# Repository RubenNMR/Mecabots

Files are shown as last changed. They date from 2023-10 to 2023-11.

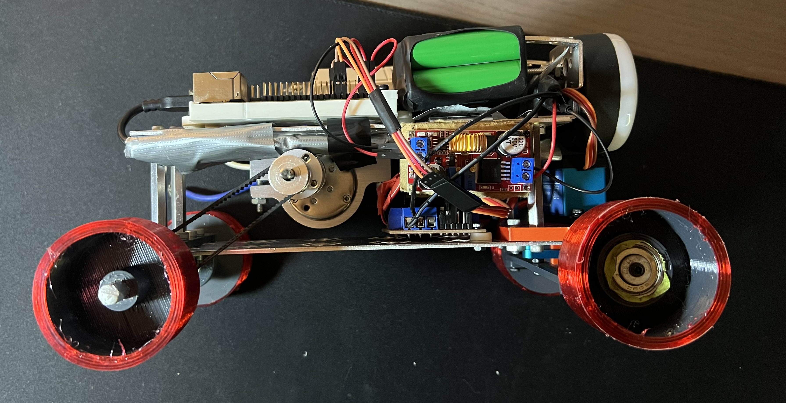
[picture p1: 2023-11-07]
v-photos/IMG_0404.jpeg

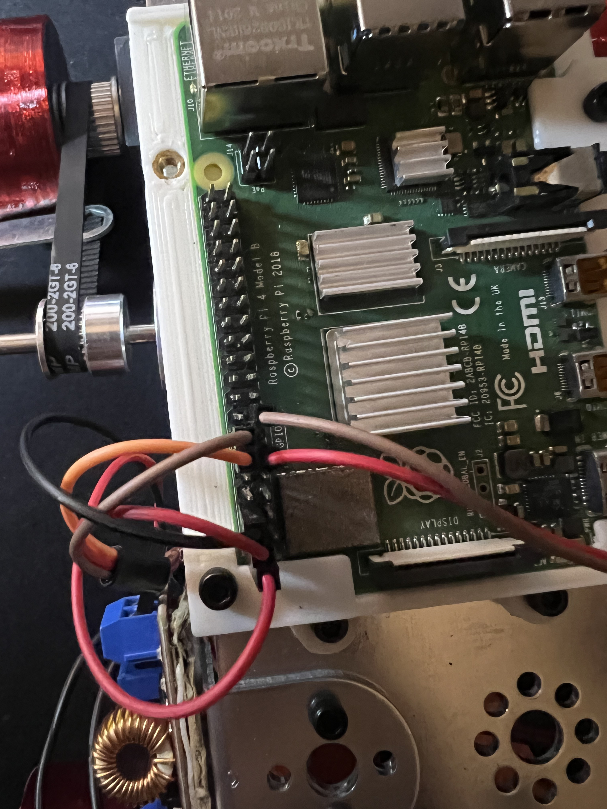
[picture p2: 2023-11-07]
v-photos/IMG_0406.jpeg

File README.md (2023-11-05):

# Vehicle Project README

## Introduction

In the making of the vehicle, we encountered many challenges that we eventually overcame. One of those challenges was the design itself. We had numerous source materials to base our project on, but we decided to innovate. We took two aluminum plates from a Tetrix kit and a motor. After we had the base, our team started a trial and error process in which we decided on our current design. The design adheres to all of the requirements of the WRO.

## Mechanical Design

When the base was completed, we started to create the front of the vehicle and all of the mechanical aspects of the steering mechanism. We designed it in SolidWorks with the help of a partner. We gave him the instructions and he assisted us with the technical aspects of using SolidWorks. Along the way, we encountered a problem with the inner workings of the steering mechanism. The issue was that the servo motor shaft was off the original position. While not immediately noticeable, we brainstormed and quickly resolved it. In the end, we sent all of the pieces to a slicer and to a 3D printer to be made.

## Construction and Adaptations

After the pieces arrived, we began the construction of the vehicle. As we progressed, we made some adjustments and changes in the design to accommodate newer parts like the motor. The motor had a shaft of 6mm, while our pulley connector was 4mm in diameter, making them incompatible. However, we were able to create an adapter using aluminum pieces that remained from the Tetrix kit.

## Software and Hardware Integration

At this point, we were simultaneously working on the software and hardware, making clear the requirements for each part and communicating any modifications that could affect either side.

## Platform Decision

We initially planned to create an Arduino white driver / Raspberry Pi hybrid, using the Arduino as a motor driver with connections to the Raspberry Pi interface, which was supposed to process and recognize obstacles. However, in the end, we decided to use only a Raspberry Pi, motor driver, and a camera. This streamlined the programming process as it was focused on a single platform.

## Power Management

To address power compatibility, we installed the motor driver's power IN into the battery and then the control pins into the Raspberry Pi. However, the Raspberry Pi can only be powered by 5 volts, not 12 volts. To overcome this, we first created a voltage regulator to reduce the output to the Raspberry Pi. After initial testing, we later purchased a more powerful and precise regulator.

## Adding Vision

With the energy source issue resolved, we needed to equip the vehicle with "eyes" - a webcam. We modified it to be more compact and easy to work with.

## Completion and Reflection

In the end, this machine was finally completed with the help of many people and a team that was united, with each member specializing in their field of knowledge but also being open to help in any way possible. This journey has led us to expand our minds and inspire us to keep pursuing what we love. We presented this project to many people, including other members of the university and even to companies like Samsung DR. However, the people who remain the most impressed by it are us, the creators: Angel Veloz, Eudy Moreno, and Ruben Martinez. We never believed that in less than one and a half months in the university, we would be creating this vehicle, and we appreciate everything. Our journey has only just begun.

## Team Information

**Names:** Angel Veloz, Eudy Moreno, Ruben Martinez

**University:** PUCMM (Pontificia Universidad Católica Madre y Maestra), Dominican Republic

**Program:** Mechatronic Engineering

## Acknowledgements

We would like to express our gratitude to the specialists in the University, including the professor of advanced Robotics, and many of the seniors who provided us with invaluable help and guidance throughout our journey.

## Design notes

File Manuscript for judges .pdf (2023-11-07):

## PONTIFICIA UNIVERSIDAD CATOLICA MADRE Y MAESTRA (PUCMM)

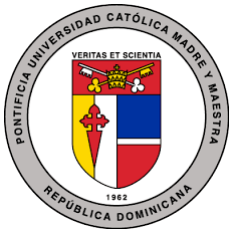
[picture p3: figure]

TEAM NAME:
MECABOT

CAREER:
MECHATRONIC ENGINEERING (IMEC)

TRAVEL MANUSCRIPT
WRO Competition

TEACHER:

IMEC DIRECTOR (JESÚS RAMÍREZ DE NAZARET)

DATE:
05/11/23 - 09/11/23

In this travel manuscript you will find the purpose of the trip, functionality of the device on board, parts with their respective links and our journey that lead us to this day.

- Materials list:
- Raspberry Pi Gen 4 (Laptop)
- Motor driver 12 volts (Motor controller)
- Energy regulator (12v - 5v energy regulator)
- Servo Motor (25kg)
- 1080p camera (generic) No link

——————————————————————————————————————————

In the making of the vehicle, we encountered many challenges that we eventually overcame. One of those challenges was the design itself. We had numerous source materials to base our project on, but we decided to innovate. We took two aluminum plates from a Tetrix kit and a motor. After we had the base, our team started a trial and error process in which we decided on our current design. The design adheres to all of the requirements of the WRO.

Mechanical Design (https://github.localhost/#mechanical-design)

When the base was completed, we started to create the front of the vehicle and all of the mechanical aspects of the steering mechanism. We designed it in SolidWorks with the help of a partner. We gave him the instructions and he assisted us with the technical aspects of using SolidWorks. Along the way, we encountered a problem with the inner workings of the steering mechanism. The issue was that the servo motor shaft was off the original position. While not immediately noticeable, we brainstormed and quickly resolved it. In the end, we sent all of the pieces to a slicer and to a 3D printer to be made.

Construction and Adaptations (https://github.localhost/#construction-and-adaptations)

After the pieces arrived, we began the construction of the vehicle. As we progressed, we made some adjustments and changes in the design to accommodate newer parts like the motor. The motor had a shaft of 6mm, while our pulley connector was 4mm in diameter, making them incompatible. However, we were able to create an adapter using aluminum pieces that remained from the Tetrix kit.

Software and Hardware Integration (https://github.localhost/#software-and-hardware-integration)

At this point, we were simultaneously working on the software and hardware, making clear the requirements for each part and communicating any modifications that could affect either side.

Platform Decision (https://github.localhost/#platform-decision)

We initially planned to create an Arduino white driver / Raspberry Pi hybrid, using the Arduino as a motor driver with connections to the Raspberry Pi interface, which was supposed to process and recognize obstacles. However, in the end, we decided to use only a Raspberry Pi, motor driver, and a camera. This streamlined the programming process as it was focused on a single platform.

Power Management (https://github.localhost/#power-management)

To address power compatibility, we installed the motor driver's power IN into the battery and then the control pins into the Raspberry Pi. However, the Raspberry Pi can only be powered by 5 volts, not 12 volts. To overcome this, we first created a voltage regulator to reduce the output to the Raspberry Pi. After initial testing, we later purchased a more powerful and precise regulator.

Adding Vision (https://github.localhost/#adding-vision)

With the energy source issue resolved, we needed to equip the vehicle with "eyes" - a webcam. We modified it to be more compact and easy to work with.

Completion and Reflection (https://github.localhost/#completion-and-reflection)

In the end, this machine was finally completed with the help of many people and a team that was united, with each member specializing in their field of knowledge but also being open to help in any way possible. This journey has led us to expand our minds and inspire us to keep pursuing what we love. We presented this project to many people, including other members of the university and even to companies like Samsung DR. However, the people who remain the most impressed by it are us, the creators: Angel Veloz, Eudy Moreno, and Ruben Martinez. We never believed that in less than one and a half months in the university, we would be creating this vehicle, and we appreciate everything. Our journey has only just begun.

Team Information (https://github.localhost/#team-information)

Names: Angel Veloz, Eudy Moreno, Ruben Martinez

University: PUCMM (Pontificia Universidad Católica Madre y Maestra), Dominican Republic

Program: Mechatronic Engineering

Acknowledgements (https://github.localhost/#acknowledgements)

We would like to express our gratitude to the specialists in the University, including the professor of advanced Robotics, and many of the seniors who provided us with invaluable help and guidance throughout our journey.

The following QR codes are meant to lead you to plataformas with more information about our vehicle.

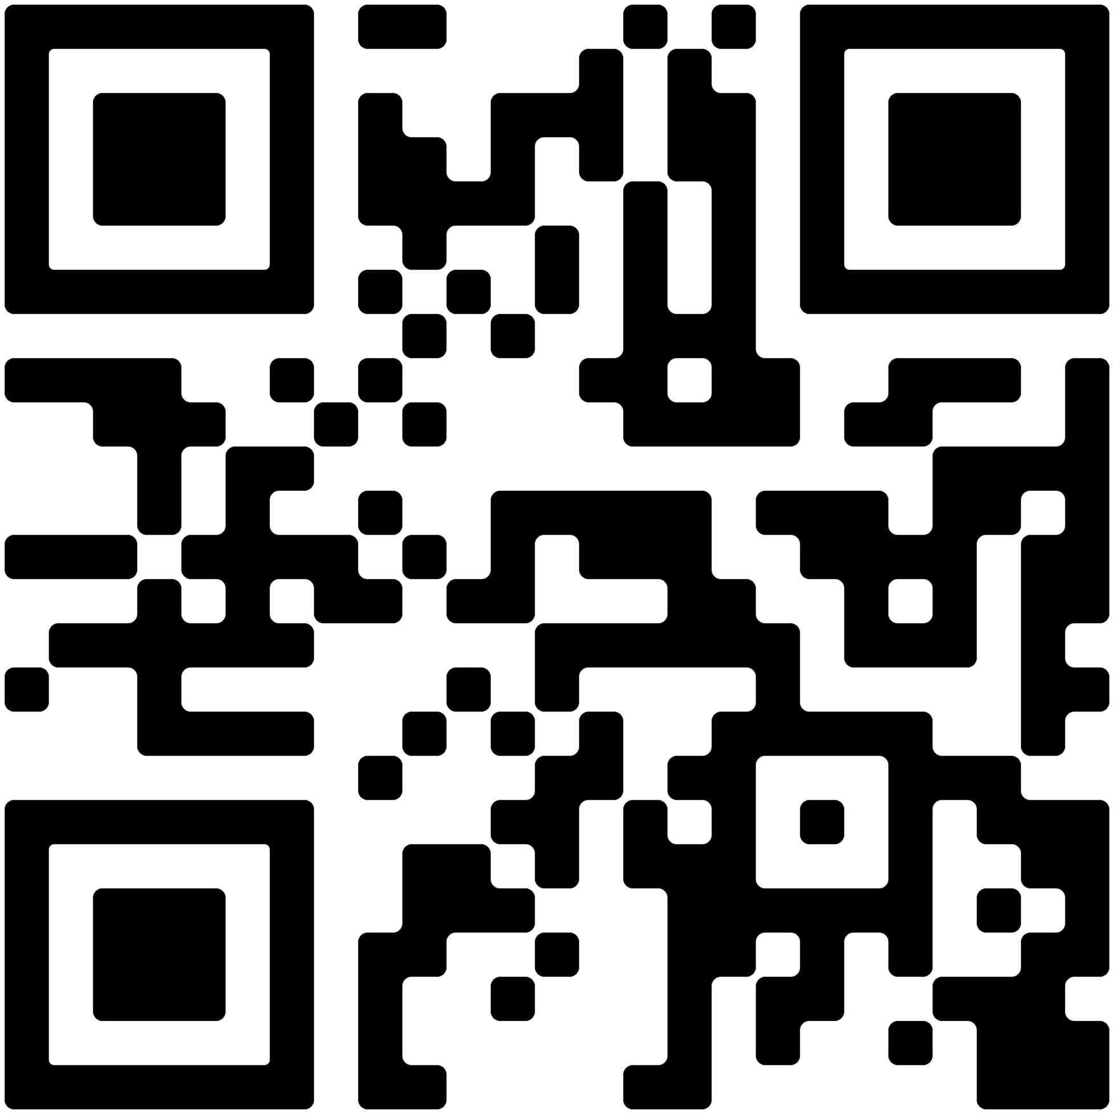
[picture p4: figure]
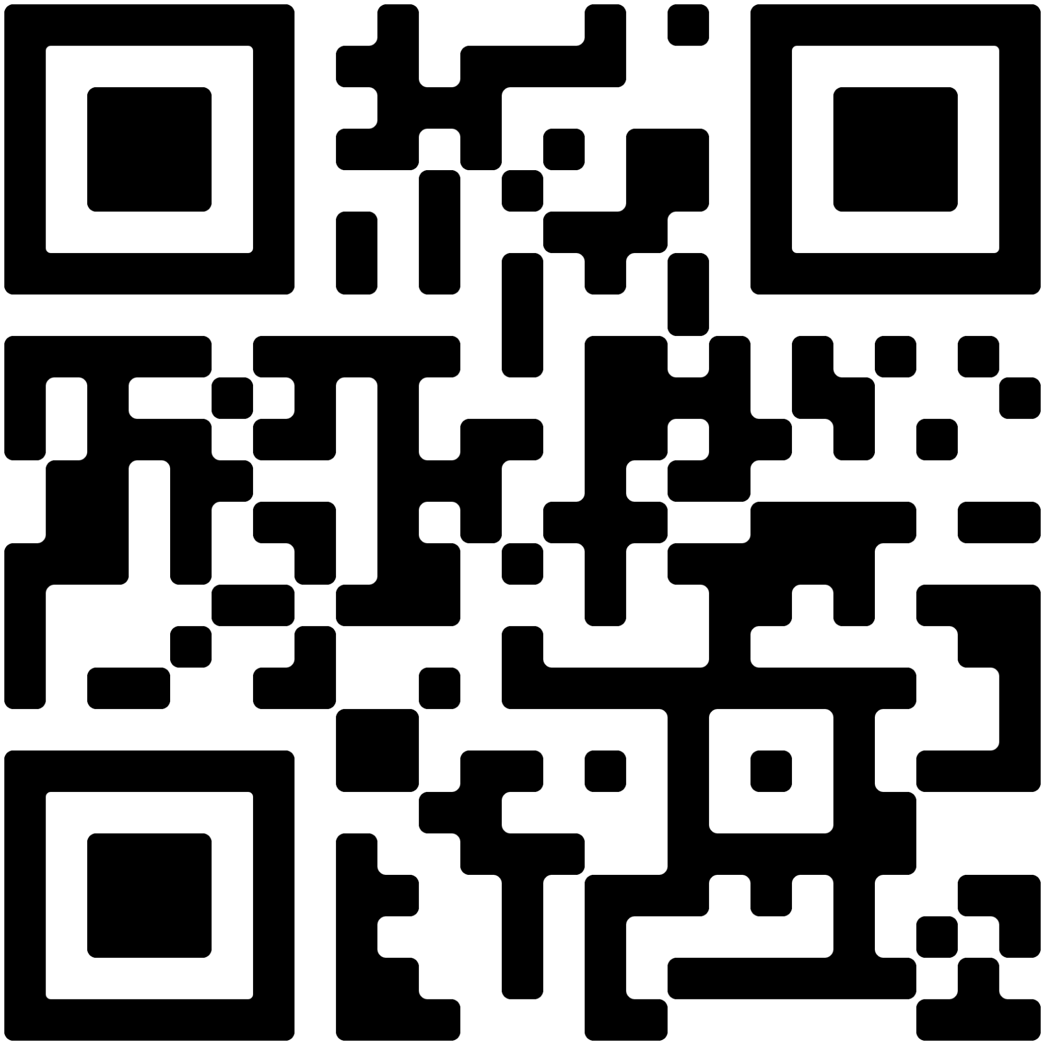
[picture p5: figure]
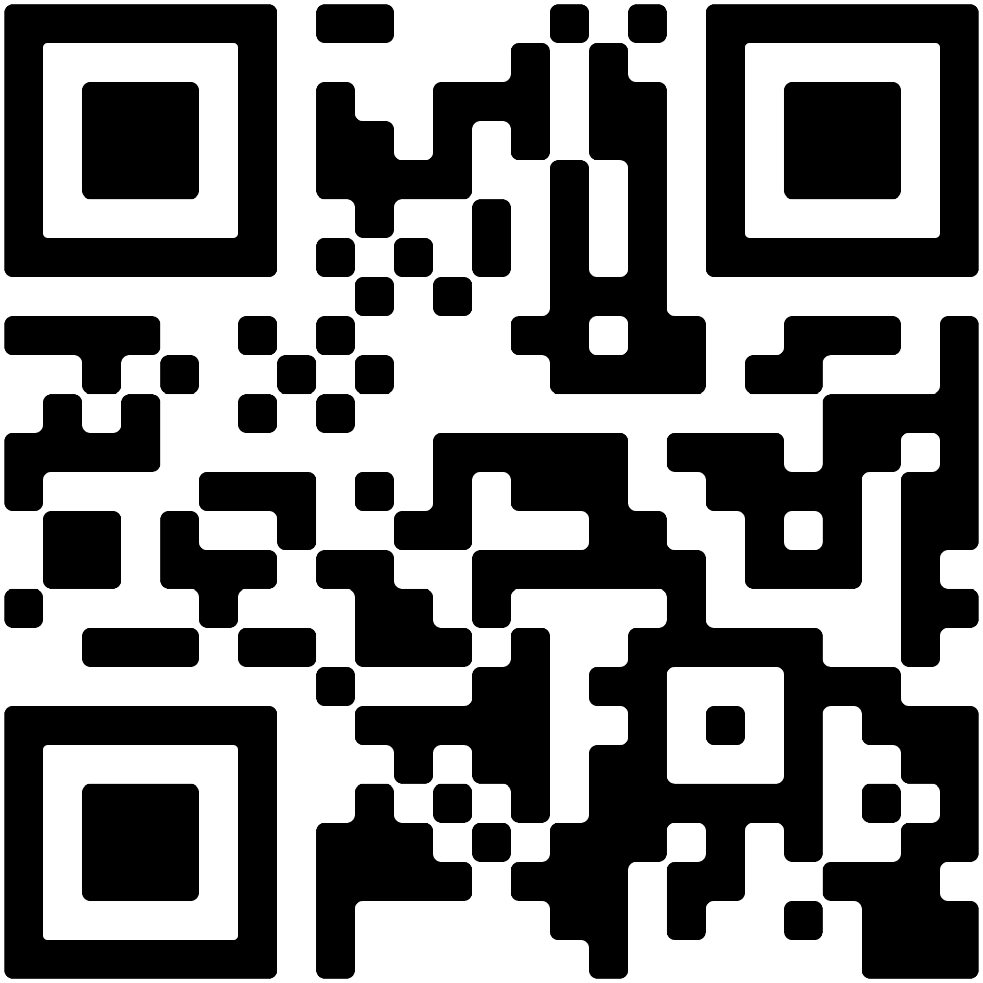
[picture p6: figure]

Energy regulator. | Servo motor. | Motor driver. | Raspberry pi Gen 4

Imágenes del robot ensamblado:

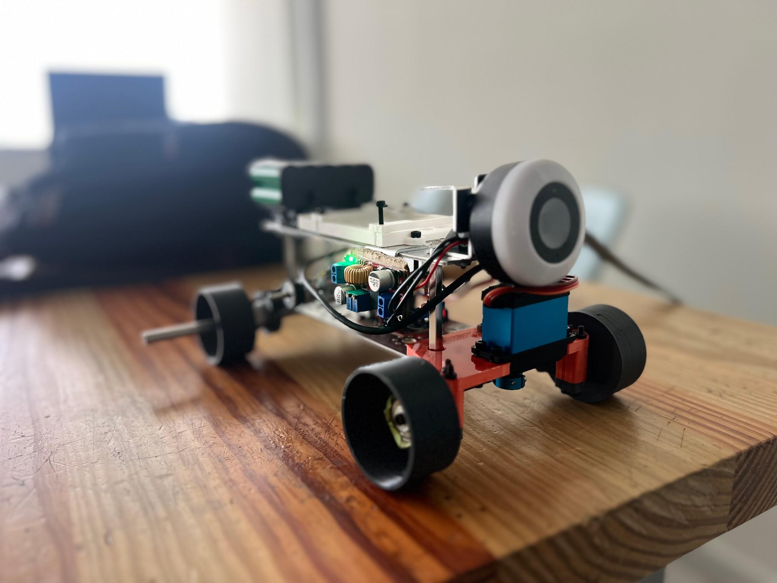
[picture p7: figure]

Ilustraciones de piezas:

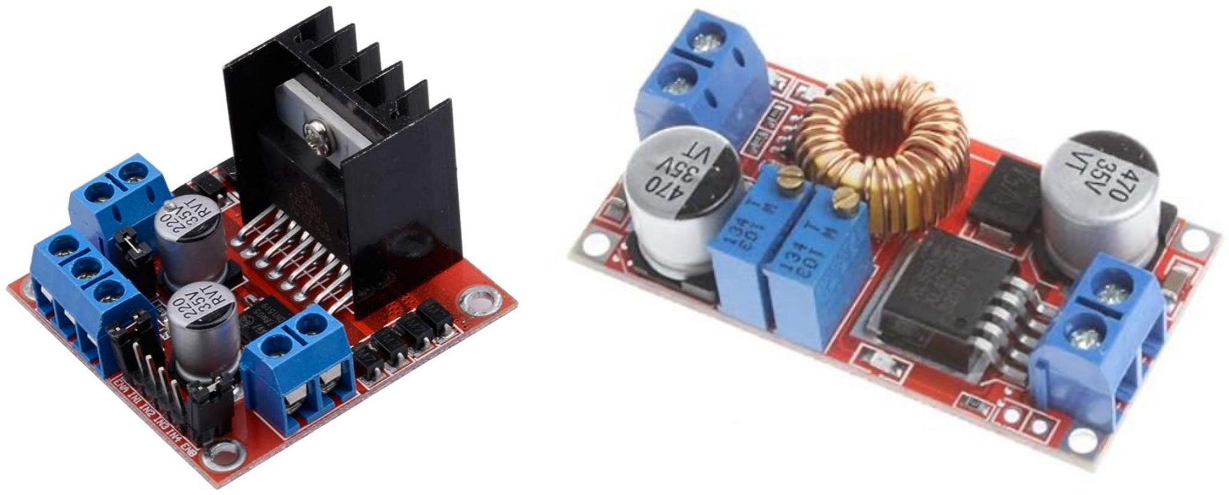
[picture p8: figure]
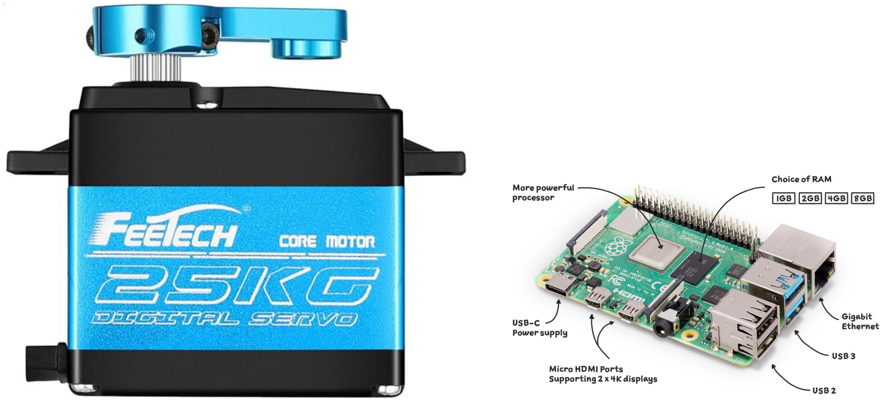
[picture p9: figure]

Gracias por su atención.

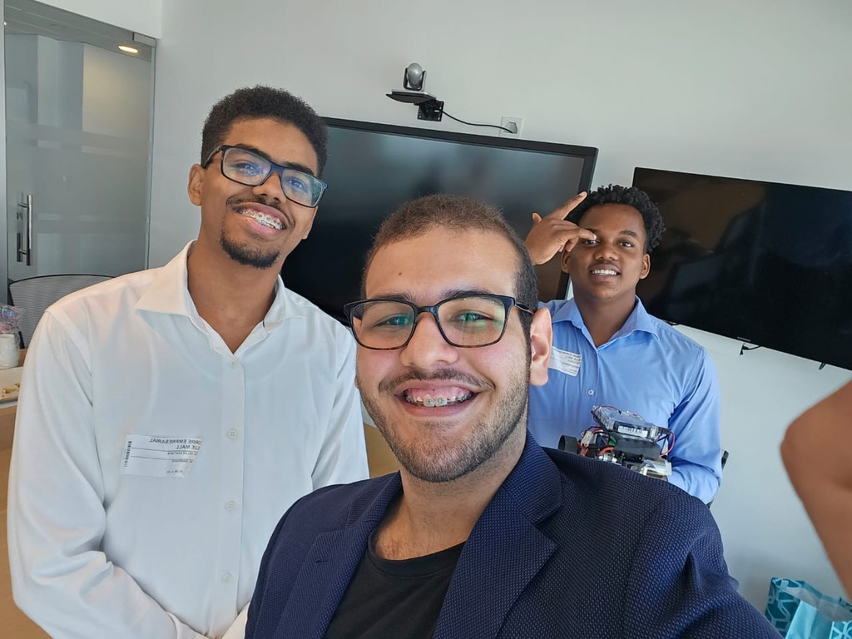
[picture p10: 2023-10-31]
t-photos/0EFD5E41-9E23-4574-BB4E-B9C148059D69_1_105_c.jpeg

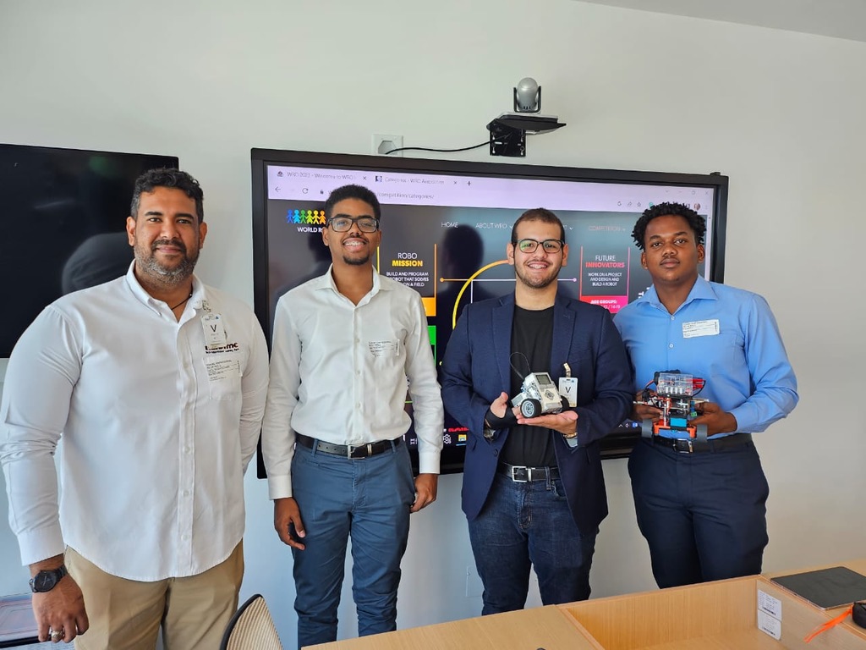
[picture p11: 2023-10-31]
t-photos/628A5C75-3474-4E2B-9B1B-85F42AEEDE7B_1_105_c.jpeg

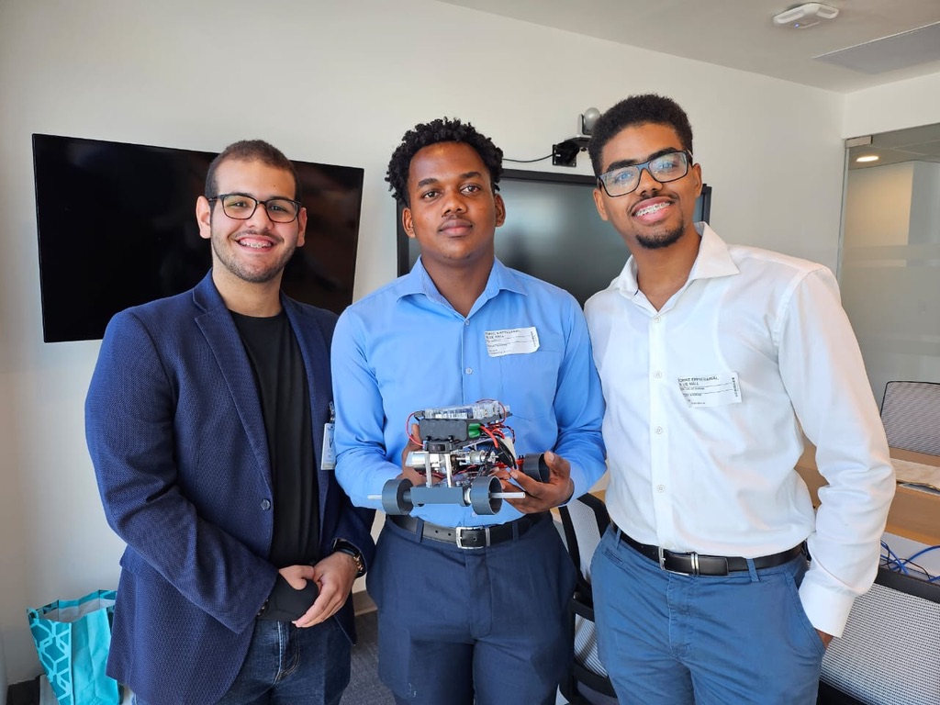
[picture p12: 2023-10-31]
t-photos/31A3FD62-FEC9-49FB-9017-C8C830B63A99_1_105_c.jpeg

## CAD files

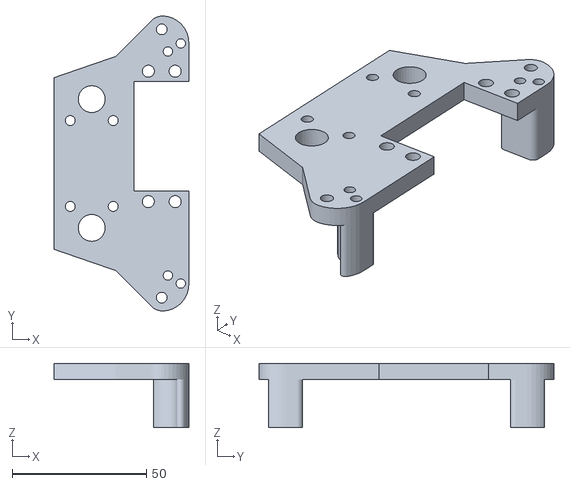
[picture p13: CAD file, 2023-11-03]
models/STL/Main Body Tren Delantero^ASS P1.STL
50.2 x 110.0 x 24.0

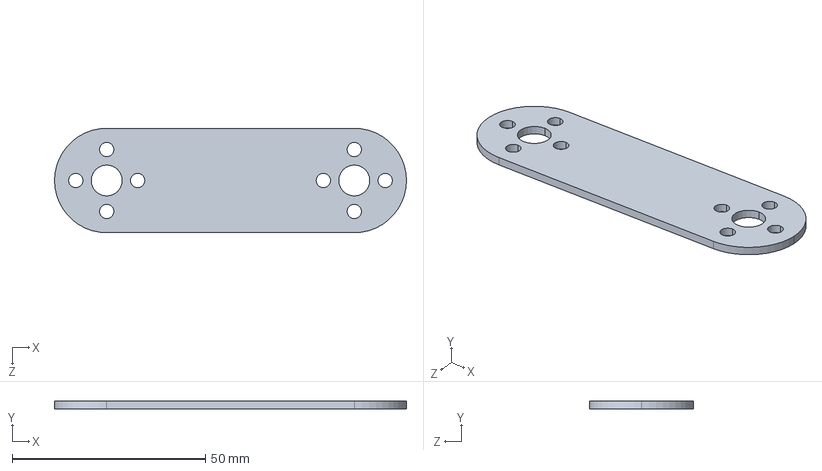
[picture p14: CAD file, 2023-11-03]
models/Flat Bracket.SLDPRT
91.0 x 2.00 x 27.0 mm

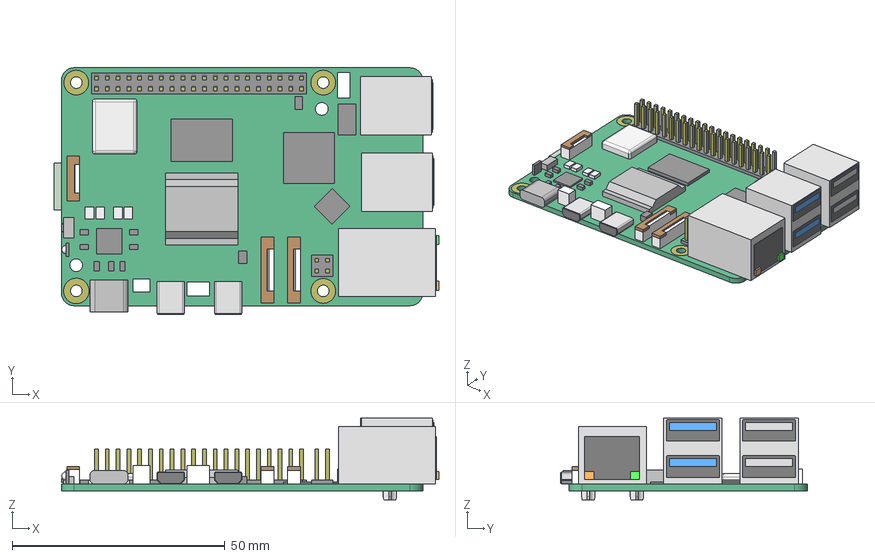
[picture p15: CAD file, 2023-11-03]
models/STEP/raspberry-pi-5-sbc-1.snapshot.2/raspberry-pi-5-sbc-simple.step
90.6 x 58.0 x 19.2 mm
connector
CSI_DSI_connector x 2
ethernet
gpio
hdmi-micro x 2
IR
mounting-holes
pcb
pcba-components Geometry
chips
pcie
pmic
poe Geometry
poe-pins
pwr-connector
rp1
sd-card
switch
uart
usb-2-bank Geometry
usb2-port x 2
usb-3-bank Geometry
usb3-port x 2
usb-c

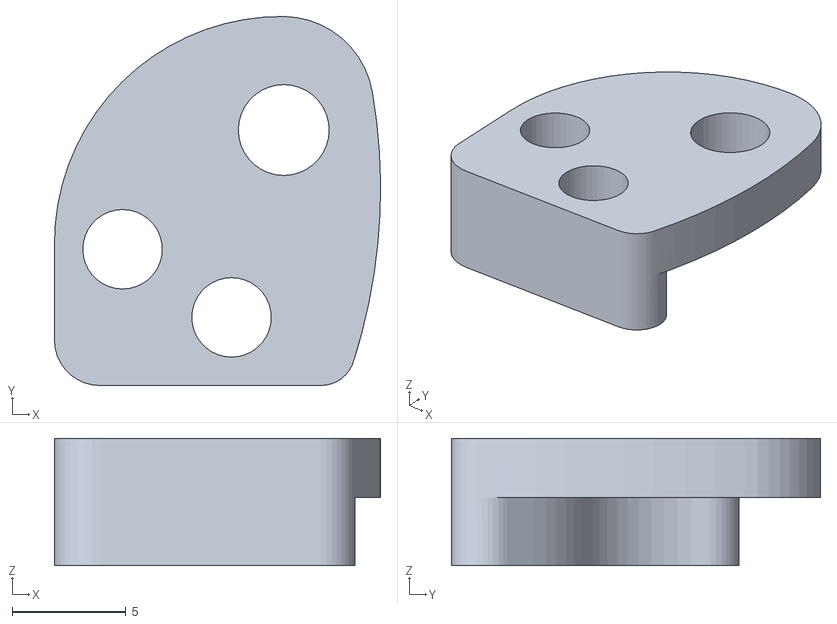
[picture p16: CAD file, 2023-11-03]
models/STL/Holder Catre^ASS P1.STL
14.4 x 16.3 x 5.60

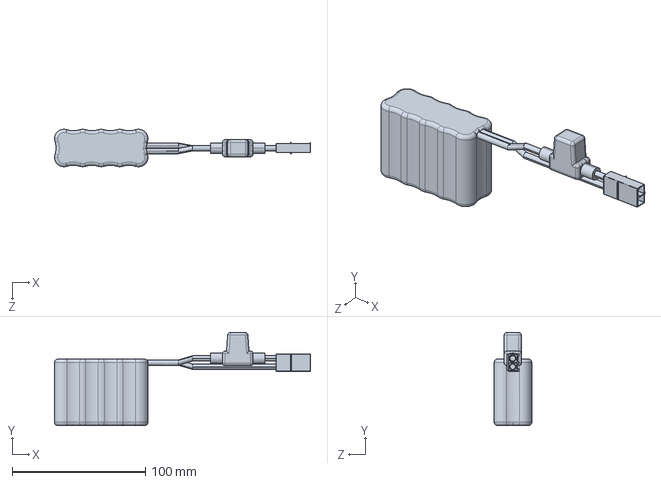
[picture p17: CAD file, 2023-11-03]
models/Bateria 12v 2000mAh.SLDPRT
192.5 x 70.0 x 28.3 mm

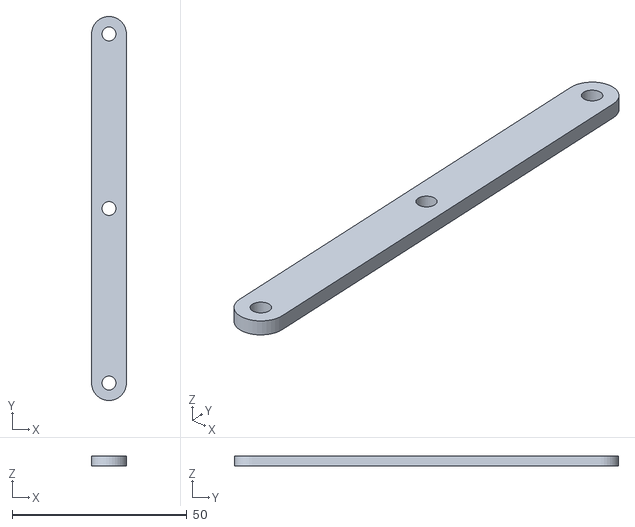
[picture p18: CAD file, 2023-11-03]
models/STL/Swing Arm^ASS P1.STL
10.00 x 110.0 x 3.00

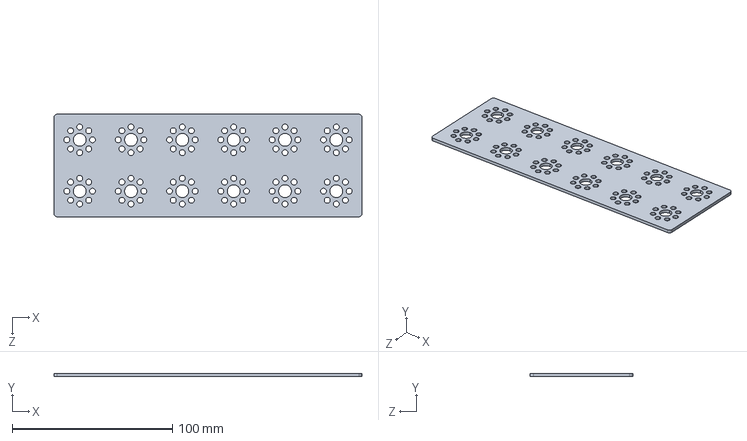
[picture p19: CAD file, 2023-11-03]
models/Plate 6x2.SLDPRT
192.0 x 2.00 x 64.0 mm

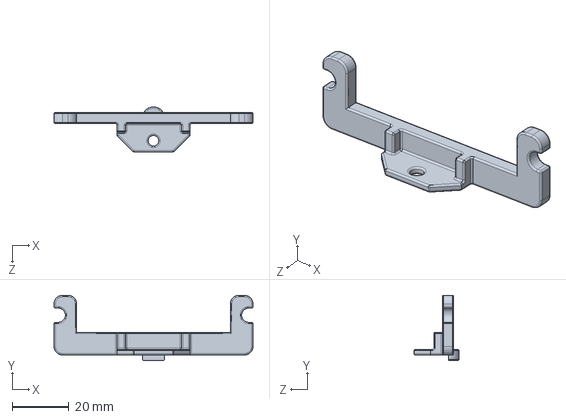
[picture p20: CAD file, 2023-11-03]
models/STEP/tx prime battery mounting bracket 40236.sldprt
70.0 x 23.0 x 15.9 mm

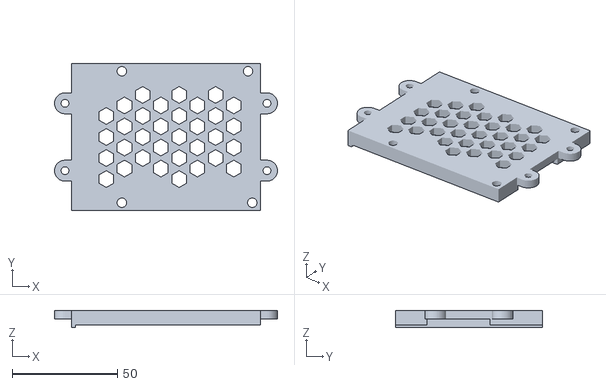
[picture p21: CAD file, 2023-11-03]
models/STL/Rpi Holder^ASS P1.STL
106.0 x 70.0 x 8.20

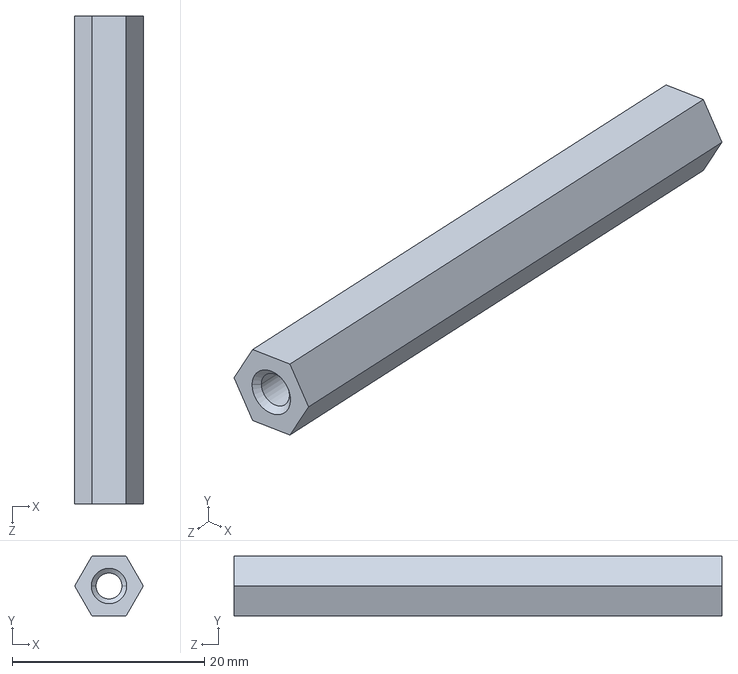
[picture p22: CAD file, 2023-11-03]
models/Standoff 2in.SLDPRT
7.16 x 6.20 x 50.8 mm

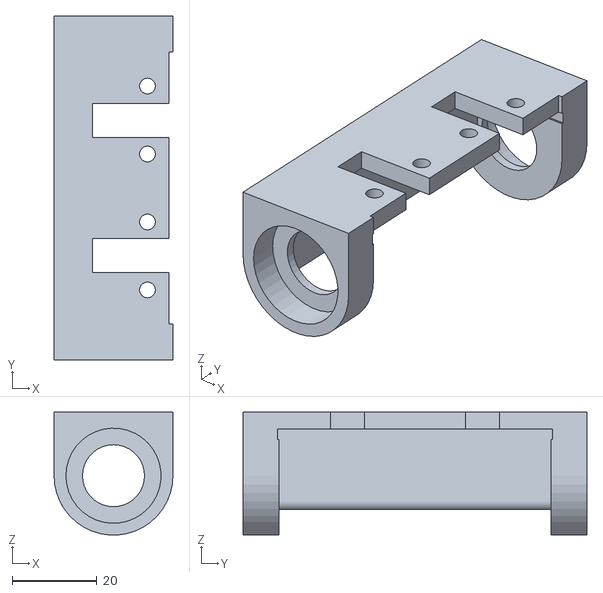
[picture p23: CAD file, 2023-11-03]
models/STL/Holder Bearings Trasero^ASS P1.STL
28.0 x 81.0 x 29.0

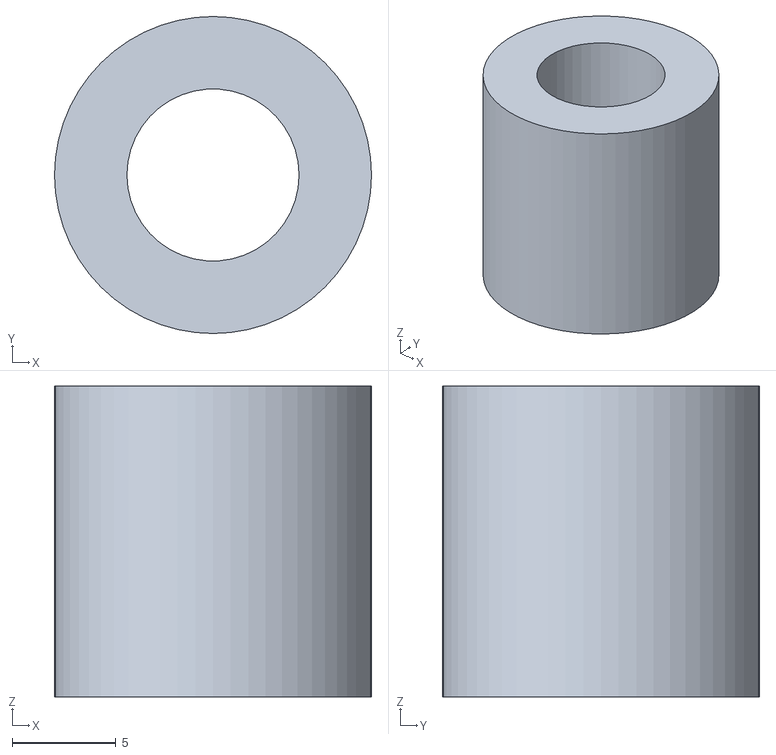
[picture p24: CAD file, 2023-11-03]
models/STL/Separador Rueda Trasera^ASS P1.STL
15.3 x 15.3 x 15.0

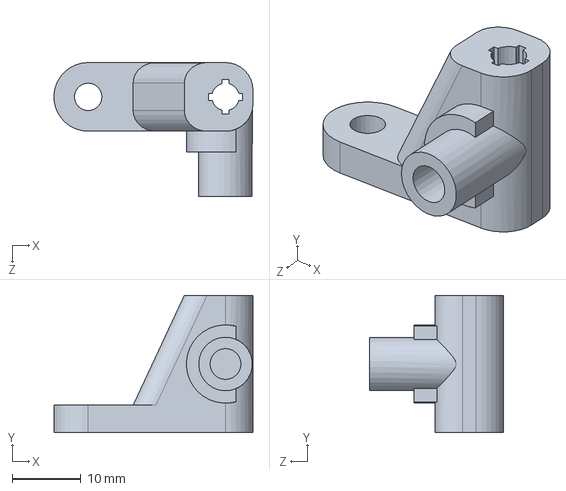
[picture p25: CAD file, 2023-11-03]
models/Catre P1.SLDPRT
29.0 x 20.0 x 19.5 mm

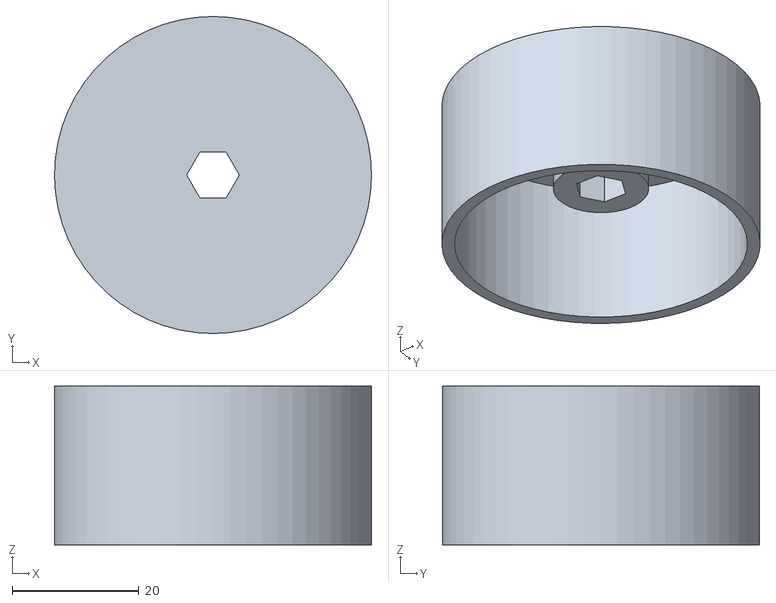
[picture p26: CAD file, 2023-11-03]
models/STL/Rueda Trasera.STL
50.0 x 50.0 x 25.0

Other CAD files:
models/STEP/RPi 5.SLDASM
models/Ass Rueda.SLDASM
models/RPi Bracket Bottom.SLDPRT
models/STL/Holder Catre Mirrored.STL
models/Battery Mount Bracket.SLDPRT
models/Goma.SLDPRT
models/STEP/41135_txm-12v 2000mah battery pack assembly.step
models/STEP/43053_maxprogrammableset/43053 MAX Programmable Set/43052_TXM PRIZM Component Set/41506_TX-GROVE ULTRASONIC RANGER.STEP
models/STEP/43053_maxprogrammableset/43053 MAX Programmable Set/43052_TXM PRIZM Component Set/41507_TX-GROVE LINEFINDER SENSOR.STEP
models/STEP/43053_maxprogrammableset/43053 MAX Programmable Set/43052_TXM PRIZM Component Set/43076_TXM-GROVE SENSOR SMALL.STEP
models/STEP/43053_maxprogrammableset/43053 MAX Programmable Set/43052_TXM PRIZM Component Set/43077_TXM-GROVE SENSOR LARGE.STEP
models/STEP/43053_maxprogrammableset/43053 MAX Programmable Set/44598_TXM CORE SET WTorqunado/38009_TXM-Structural Mount for NIMH Pack.STEP
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

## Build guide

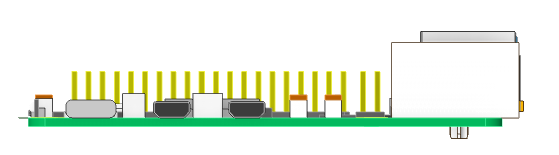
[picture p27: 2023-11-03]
models/STEP/raspberry-pi-5-sbc-1.snapshot.2/pi5-sbc-side-OK6Llj89xO.png

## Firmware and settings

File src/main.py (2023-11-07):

# TODO: Check if we have to change lanes while we turn and implement that thing.
# TODO: Measure the actual block with on proper distances.
# TODO: Properly implement odometry
# TODO: Implement bot.changeLane function
# TODO: Measure the turning values for the corners
# TODO: Implement proper motion.

from Robot import Robot
from masking import block_detector, line_detector, Camera, block_width, np

bot = Robot()
cam = Camera()
killsig = 0
turn_thres = 30
min_line_len = 500

frame = np.zeros([480, 640, 3])
waypoints = [0, 90, 180, 270]  # these are the edges to turn.
turn_count = 0
current_point = 0
v, omega = 0, 0
target_line = "orange"
state = "straignt"
lane = "left"
angle = 0
corners = 0

try:
    while not killsig:
        # Inputs
        frame = cam.read()
        frame = frame[len(frame) // 2:]
        target_point = waypoints[current_point+1]
        lines = line_detector(frame)
        w = bot.omega

        # logic to decide the next move
        # First, see if we have to turn

        if state == "straight":
            # Check if we must turn
            for line_set in lines:
                if line_set[1] == target_line:
                    for line in line_set[0]:
                        if ((line[1][0] - line[0][0]) ** 2 + (line[1][1] - line[0][1]) ** 2) ** 0.5 > min_line_len:
                            state = "turning"
                            v = 1
                            omega = 1 if target_line == "orange" else -1
                            corners += 1
                            break
                    break

            if state == "straight":  # If we didn't turn:
                blocks = block_detector(frame)  # This returns the bounding boxes
                # Go through all detected blocks
                for box, name in blocks:
                    if name == "red":
                        if lane == "right":
                            v, omega = 1, 0
                        else:
                            if box[2] > block_width:
                                bot.changeLane("left")
                                break

                    elif name == "blue":
                        if lane == "left":
                            v, omega = 1, 0
                        else:
                            if box[2] > block_width:
                                bot.changeLane("right")
                                break

        if state == "turning":  # if we found that we have to turn
            target_angle = waypoints[angle % 4]  # get the goal angle
            if target_line == "orange":
                # Decrementing angles
                # this is clockwise
                if w > target_angle:
                    pass
                else:  # We're done turning
                    v, omega = 0, 0  # stop
                    state = "straight"
                    angle -= 1
            elif target_line == "blue":
                # incrementing angles
                # this is ccw
                if w < target_angle:
                    pass
                else:  # We're done turning
                    v, omega = 0, 0
                    state = "straight"
                    angle += 1

        # Outputs
        bot.move(v, omega)
        killsig = 0 if turn_count < 3 else 1



except KeyboardInterrupt:
    cam.stop()
    bot.exit()

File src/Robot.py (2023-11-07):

from gpiozero import Device, AngularServo, Motor  # Librerias para controlar dispositivos
from gpiozero.pins.pigpio import PiGPIOFactory  # Recomendado por la libreria para reducir vibraciones del servo
from threading import Thread
from time import sleep, time
import math
Device.pin_factory = PiGPIOFactory()  # no le des mucha mente
# btw esto requiere instalar pigpio por pip y usar el siguiente comando:
"sudo systemctl enable pigpiod"

# Angular: 15s (14.95) for 1 total circle
# Linear: for 59cm, 3.55 seconds
# Diameter of turning circle: 83cm


class Robot:
    def __init__(self, in1=17, in2=22, servo=18):
        self.motor = Motor(in1, in2)
        self.servo = AngularServo(servo, min_pulse_width=0.0005, max_pulse_width=0.0025)  # Ancho de pulsos PWM
        self.servo.angle = 15  # Poniendo el servo en midship (midship=centro)
        self.v, self.omega = 0, 0
        self.stop_flag = 0
        self.x, self.y, self.w = 0, 0, 0
        self.max_linear_speed = 59 / 3.55  # Linear speed in cm per second
        self.max_angular_speed = (2 * math.pi * 41.5) / 15  # Angular speed in radians per second
        Thread(target=self._move, daemon=True).start()

    def _move(self):
        stop = 0
        prev = time()
        while not stop:
            if self.stop_flag:
                if not self.v and not self.omega:
                    self.v, self.omega = 0, 0
                else:
                    stop = 1
            dt = time()-prev
            prev = time()
            # Primero aseguramos que los valores esten entre -1 y 1
            v = min(max(-1, self.v), 1)
            omega = min(max(-1, self.omega), 1)
            self.servo.angle = 30*omega+15  # Mapear valores entre -1 a 1 -> -15 a 45
            self.motor.value = v
            # Esto usa algo llamado setters. Basicamente es una manera especial de llamar una funcion
            # En vez de self.motor.value(v), se asigna como si fuera una variable, y en la libreria eso ajusta el motor
            # Lo mismo con el servo
            # odometry goes here
            self.odom(dt)
            sleep(0.1)

    def move(self, v=0, omega=0):
        self.v, self.omega = v, omega
        sleep(0.1)

    def exit(self):
        # Esto es para luego, por si se necesita.
        self.stop_flag = 1
        self.move()
        self.servo.close()
        self.motor.close()
        pass

    def changeLane(self, side):
        pass

    def odom(self, dt):
        # Calculate linear speed (v) and angular speed (omega) based on servo angle and motor speed
        v = self.v * self.max_linear_speed  # Adjust max_linear_speed as needed
        omega = -self.omega * self.max_angular_speed  # Adjust max_angular_speed as needed, and negate for counterclockwise rotation

        # Calculate change in x, y, and theta
        self.x += v * math.cos(omega) * dt
        self.y += v * math.sin(omega) * dt
        self.w += omega * dt
        print(f"dT: {dt}, X: {self.x:.5f}cm, Y: {self.y:.5f}cm, W: {self.w:.5f} radians")


if __name__ == '__main__':
    from networktables import NetworkTables as nt
    nt.initialize()
    bot = Robot()
    controller = nt.getTable("controller")
    while True:
        omega = controller.getNumber("omega", 0)
        v = controller.getNumber("v", 0)
        bot.move(v, omega)
